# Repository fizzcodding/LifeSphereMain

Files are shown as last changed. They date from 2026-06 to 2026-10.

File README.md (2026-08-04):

# LIFESPHERE

**Health · Safety · Automation · Care**

> *An AI-Powered Autonomous Caregiving Ecosystem*

**Research paper:** [`An AI- Powered Autonomous Caregiving Ecosystem.pdf`](./An%20AI-%20Powered%20Autonomous%20Caregiving%20Ecosystem.pdf)
**Live web demo:** <https://spherecore-lite.vercel.app> — the deployed web demo; switch between App Mode and Result Mode in the header
**Android APK:** [app-release.apk](./spherecore/build/app/outputs/apk/release/app-release.apk)

What's built and working right now is SphereCore, in two forms. The Flutter companion app is the primary one, and the web demo in `hollowcore-hardware/web_demo/` is its browser counterpart with two modes: **App Mode** is a web reimplementation of SphereCore's Firebase-backed screens, so it's the same app, not a separate tool — and **Result Mode** is a read-only live mirror of HollowCore's state, updating in real time as control actions land from SphereCore (mobile or App Mode). Everything runs on the one Firebase Realtime Database backend, which is what makes a toggle in one surface show up in the others. LifeSphere as a whole is the larger goal: an autonomous caregiving ecosystem of five subsystems sharing one biological state, monitoring the user across four dimensions (medical, physical, emotional, environmental) and responding without explicit input. The whole point is that the user never has to touch a screen or say a command — the system watches their biology and reacts to that instead. The remaining subsystems are documented and scaffolded but not yet migrated in (see [Project Status](#project-status)).

## Contents

- [Local Development Setup](#local-development-setup)
- [SphereCore](#spherecore)
- [Why LifeSphere?](#why-lifesphere)
- [The Five Subsystems](#the-five-subsystems)
- [System Architecture](#system-architecture)
- [AI Model Pipeline](#ai-model-pipeline)
- [Key Features](#key-features)
- [Bill of Materials](#bill-of-materials)
- [Repository Layout](#repository-layout)
- [Project Status](#project-status)

## Local Development Setup

Here's how to get SphereCore running locally. Requires the [Flutter SDK](https://docs.flutter.dev/get-started/install) (Dart SDK `^3.10.8` per `pubspec.yaml`).

```bash
git clone https://github.com/fizzcodding/LifeSphereMain.git
cd LifeSphereMain
```

```bash
cd spherecore
flutter pub get
flutter run                      # picks a connected device / emulator
flutter build apk --release      # Android release build
```

Firebase is the backend. The repo ships with `lib/firebase_options.dart` for the `hollow-core` project; to point the app at your own Firebase project, run `flutterfire configure` and set up a Realtime Database following the LifeSphere schema (see Section 7 of the [research PDF](./An%20AI-%20Powered%20Autonomous%20Caregiving%20Ecosystem.pdf)). Note that the camera view (`ControlScreen`) and member management (`MembersScreen`) talk to hardware over the local network — an ESP32-CAM websocket on port 81 and an HTTP endpoint — so those screens won't do anything useful without the physical hardware on the same LAN.

### HollowCore web demo

The web demo runs locally too (Vite + Firebase JS SDK, needs Node.js and npm). It signs in against the same Firebase project as the app, so an account registered on mobile works here directly:

```bash
cd hollowcore-hardware/web_demo
cp .env.example .env     # Firebase web config; values mirror spherecore/lib/firebase_options.dart
npm install
npm run dev              # dev server on http://localhost:5180
```

Once it's up you'll see a mode switch in the header. **App Mode** is a read/write web version of SphereCore's Firebase-backed screens (Devices, Vital32, Reminders, Profile) — writes go to the same database paths the mobile app uses, so toggling a device here drives real hardware. **Result Mode** is a read-only mirror: toggle something from the mobile app and the corresponding tile flashes and logs the change within milliseconds, nothing polled or simulated. More detail (data model, which SphereCore screens are deliberately not reimplemented and why) in [`hollowcore-hardware/web_demo/README.md`](./hollowcore-hardware/web_demo/README.md).

## SphereCore

Since the elderly user is meant to never touch a screen, the app is the window in for guardians and family members instead. It streams the shared biological state object from Firebase Realtime Database into a live dashboard (heart rate, SpO₂, skin temperature, HRV, anomaly score, emotional state, subsystem statuses), manages medication schedules produced by the prescription OCR pipeline before HollowRover starts delivery, and controls HollowCore appliances and ecosystem modes such as Absence Mode. Guardians can add dependent members, define monitoring instructions and receive alerts for falls, intrusions, anomalies, and digital-safety events. The Flutter app builds for Android, iOS, web, and desktop, with Android as the primary target; the web demo's App Mode covers its Firebase-backed screens in the browser.

Full details, screens, and project structure: [`spherecore/README.md`](./spherecore/README.md)

## Why LifeSphere?

Bangladesh has over 15 million elderly citizens, most of whom stay home alone while family members work full-time. Every day people forget critical medication, fall with nobody nearby, and deteriorate physically and emotionally until it turns life-threatening.

**Hypothesis:** an integrated, bioresponsive caregiving ecosystem produces better outcomes than any combination of single-function devices.

Existing smart devices work in silos, a smartwatch tracks heart rate, a smart speaker sets reminders, a camera records video, and none of them talk to each other. LifeSphere ties everything to a single biological state backbone: when Vital32 detects a cortisol spike, SphereAI adjusts its tone, HollowCore changes the lighting, and HollowRover prepares a stress-relief protocol, all automatically.

## The Five Subsystems

| Subsystem | Primary Function | Core Hardware | AI Stack | Repo Directory |
|---|---|---|---|---|
| **Vital32** | Continuous biometric monitoring & home automation trigger | ESP32, MAX30102, MPU6050, MLX90614, BME688, BIA circuit (16-sensor array) | LSTM, Isolation Forest, biological age model | [`vital32/`](./vital32) |
| **HollowRover** | Physical response, medicine delivery, security patrol, passive barrier deterrence | D-Robotics RDK X5 (4GB, 10 TOPS NPU), STL-19P TOF LiDAR, DW1000 UWB, MLX90640 thermal, 6-DOF MG996R arm | SLAM, Nav2, biomarker-triggered protocol engine, DeepFace | [`hollowrover/`](./hollowrover) |
| **SphereAI** | Trimodal emotional intelligence & cognitive monitoring | Microphone, speaker, Whisper STT, OLED via rover | NLP + voice prosody + biomarker fusion classifier | [`sphereai/`](./sphereai) |
| **EntryGuard** | 24/7 intrusion, fire, and gas detection at all entry points | PIR, MQ-2 gas, KY-026 fire, ESP32 nodes | DeepFace recognition, threat classification | [`entryguard/`](./entryguard) |
| **HollowCore** | Biology-responsive home & financial automation | Wi-Fi relay modules, MQTT broker, ESP32 | Biomarker-to-environment mapping, anomaly detection | [`hollowcore-hardware/`](./hollowcore-hardware) |

### Vital32 — The Sensing Layer

A wearable the user forgets they're wearing. Its 16-sensor array captures ECG waveforms, IR skin temperature, accelerometer/gyroscope data (fall and tremor detection), bioelectrical impedance (hydration), galvanic skin response (sympathetic nervous activity), and near-infrared tissue perfusion (wound healing). The onboard AI pipeline is designed to flag immune activation 24–48 hours before symptoms appear and estimate pre-seizure probability 30 minutes before onset.

### HollowRover — The Physical Response Unit

Runs ROS2 Humble on a D-Robotics RDK X5, with SLAM floor mapping and UWB positioning targeting 10 cm accuracy. It executes biomarker-triggered protocols on its own: medication dispensing, fall response dispatch, pre-seizure cushioning, and cortisol-spike deescalation. The 6-DOF arm picks up dropped objects and hands items to the user. As a security deterrent it is passive-barrier only. No contact, no restraint, and any escalation requires human authorization.

### SphereAI — The Emotional Intelligence

A TriAgent architecture: NLP sentiment analysis, vocal prosody extraction, and live Vital32 biomarker feeds, fused by a dynamically weighted meta-classifier. This supports early cognitive decline detection and longitudinal emotional modeling. It also includes an Islamic integration framework: Salah reminders, stress-triggered Adhkar, and a Ramadan mode that restructures medication and hydration around fasting.

### EntryGuard — Perimeter Security

Multi-sensor ESP32 nodes (PIR, ultrasonic, fire, gas) at every entry point, with face recognition checked against registered profiles. It arms itself and only alerts on genuine threats.

### HollowCore — Biology-Responsive Automation

Maps physiological and emotional state directly to lighting, thermal, appliance, and digital safety outputs over Wi-Fi + MQTT. Stressed → lights dim. Cold → AC adjusts. The design also covers financial anomaly detection (Isolation Forest on spending habits) with multi-factor biometric transaction authorization.

## System Architecture

- **Shared Biological State Object** — a continuously updated JSON document on Firebase Realtime Database, the ecosystem's central nervous system. Vital32 writes, everything else subscribes (target latency: 150 ms).
- **Two-channel communication** — cloud-mediated Firebase listeners plus direct MQTT over local Wi-Fi; a 115200-baud serial bridge for sub-10ms motor commands; GSM (SIM800L) fallback during Wi-Fi outages.
- **Multi-timescale inference** — short-cycle (30 s) acute anomaly detection, medium-cycle (15 m) emotional/cortisol models, long-cycle (24 h) biological age clock and circadian modeling.
- **Fault tolerance** — 5000 mAh backup battery, 24 h local SD vital storage, HollowRover doubles as a local hotspot during outages, independent watchdog timers on all five nodes.
- **Security** — TLS in transit, face profiles stored locally (never uploaded), mandatory human authorization before any defensive action, physical-plausibility validation of all sensor readings.

## AI Model Pipeline

| Model | Architecture | Output | Threshold |
|---|---|---|---|
| Anomaly Detector | Isolation Forest (100 trees) | Score 0–1 | 0.7 / 0.9 |
| Pre-Seizure LSTM | 2×LSTM (64, 32) + Dense | Prob 0–1 | 0.85 |
| Emotional Classifier | Weighted 3-stream fusion | State category | Highest |
| Cortisol Estimator | Gradient Boost (200 trees) | ng/dL est. | 15 m update |
| Biological Age Clock | Ensemble (RF + XGBoost) | Age in years | Daily update |
| Cognitive Tracker | Statistical drift (CUSUM) | Deviation score | 2-sigma |

All models are trained offline and run on-device as TensorFlow Lite. They learn the user's own biological baseline over the first 30 days instead of comparing against a generic population.

## Key Features

- **Prescription OCR** — photograph a prescription once; OCR + LLM parsing builds the full medication schedule and syncs it to HollowRover's dispenser, with pressure-sensor adherence logging.
- **Absence Mode** — runs the household while the occupant is away: plant watering, appliance checks, patrols, full-active security, and daily photo/status reports.
- **Remote Guardian** — guardians configure monitoring for dependent family members remotely, including AI-powered digital safety (network-level content filtering, smart screen time, distress-pattern alerts).

## Bill of Materials

| Subsystem | Cost (USD) |
|---|---|
| Vital32 | $67.70 |
| HollowRover | $373.30 |
| SphereAI | $12.00 |
| EntryGuard (×2 nodes) | $36.50 |
| HollowCore | $15.00 |
| **LifeSphere Total** | **$504.50** |

## Repository Layout

```
LifeSphereMain/
├── vital32/                  # ESP32 biosensing wearable (firmware, TFLite models, web demo)
├── hollowrover/              # ROS2 rover workspace, dispenser + ESP32 peripheral sketches
├── sphereai/                 # TriAgent emotional intelligence (Python)
├── entryguard/               # ESP32 perimeter security nodes + face recognition API
├── hollowcore-hardware/      # ESP32 relay firmware, automation logic, web control panel
├── spherecore/               # Flutter companion app (dashboard, reminders, control)
├── MedicineDispenser.FCStd   # FreeCAD model of the medication dispenser
├── ResearchPaper.latex       # Research paper source
└── An AI- Powered Autonomous Caregiving Ecosystem.pdf   # Full build document
```

## Project Status

This is an active competition-stage project, not a finished product. Current state of the code, honestly:

- **Working end to end:** SphereCore in both its forms (Flutter app and the web demo's App Mode / Result Mode), plus the HollowCore ESP32 relay firmware. All of it reads and writes the same Realtime Database, so an appliance toggled in any one surface moves real hardware and shows up in the others.
- **Scaffolded:** the source trees for Vital32, HollowRover, SphereAI, and EntryGuard exist with their intended file layout, but most files are placeholders pending migration of the working code. The hardware builds, sensor integrations, and model designs for these subsystems are documented in the research PDF.
- The performance figures quoted above (150 ms sync latency, 10 cm UWB accuracy, pre-symptom detection windows) are design targets and prototype measurements from the research document, not guarantees of the code in this repo.
- The release APK linked at the top of this page lives under `spherecore/build/`, which is a build-output directory; rebuild with `flutter build apk --release` if it's absent from your checkout.

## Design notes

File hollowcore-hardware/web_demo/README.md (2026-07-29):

# HollowCore Web Demo

Browser control panel for the HollowCore automation node. It authenticates against the
same Firebase project as the SphereCore Flutter app (`hollow-core`), so an account
registered on mobile signs in here with no separate user record.

## Setup

```bash
cd hollowcore-hardware/web_demo
cp .env.example .env
npm install
npm run dev
```

The dev server listens on <http://localhost:5180>.

`.env` is gitignored. The values in `.env.example` mirror the web block of
`spherecore/lib/firebase_options.dart`, plus `VITE_FIREBASE_DATABASE_URL`, which the
Flutter SDK derives from the project ID but the JS SDK requires explicitly.

## Modes

The header carries an explicit **App Mode / Result Mode** switch. The selection persists
in `localStorage`.

**App Mode** is a read/write reimplementation of the SphereCore screens that are backed
by Firebase: Devices, Vital32, Reminders and Profile. Writes go to the same Realtime
Database paths the mobile app writes to, so toggling a device here drives real hardware.

**Result Mode** is a read-only mirror driven by `onValue` listeners. Toggle a device in
the mobile app and this view updates within milliseconds: the affected tile flashes, an
`UPDATED` badge appears, and a timestamped entry lands in the change feed. Nothing is
polled and nothing is simulated.

Two SphereCore screens are deliberately not reimplemented. `ControlScreen` talks to an
ESP32-CAM over `ws://<lan-ip>:81` and an MJPEG stream, and `MembersScreen` calls
`http://<lan-ip>/users`. Both require the reviewer to be on the same LAN as the hardware,
so they cannot work from a remote browser.

## Architecture

```
src/
  firebase/    SDK initialisation and env-backed config
  auth/        sign-in, registration, session observation
  api/         Realtime Database paths and read/write services
  realtime/    onValue subscriptions, connection monitor, pin diffing
  ui/          shell, views, reusable components
  lib/         DOM helper and formatting
  styles/      design tokens translated from spherecore AppTheme
```

The layers only depend downwards: `ui` uses `api` and `realtime`, both of which use
`firebase` and `auth`. No view talks to the Firebase SDK directly.

## Data model

Device state lives at `users/{uid}/virtualPins/{pushId}`:

```json
{ "id": "-OWLbEYsujEjrFI6SEIs", "label": "Living room light", "pin": 26, "state": false }
```

`pin` is the ESP32 GPIO number and `state` is the relay's desired level. The record's
`id` field is not authoritative; some existing rows carry a stale value, so the push key
is used instead, matching `DatabaseService.getPins()` in the Flutter app.

## Design tokens

Colours, fonts and radii are taken from `spherecore/lib/themes/app_theme.dart` and
declared as CSS custom properties in `src/styles/base.css`. SphereCore ships a light
theme (`themeProvider` is hardcoded to `ThemeMode.light`), so this panel is light too.
Poppins and the LifeSphere logos are copied from `spherecore/assets`; the logos are
cropped to their content bounds because the originals are centred on 500x500 canvases.

## Security

`database.rules.json` in the parent directory scopes every read and write to the owning
user. Deploy it before demoing:

```bash
firebase deploy --only database --project hollow-core
```

Without it the database is world-readable.

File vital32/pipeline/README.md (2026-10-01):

# Vital32 AI Model Training Pipeline

Offline model training and TFLite export pipeline for the Vital32 wearable biosensor node (LifeSphere project). Models are trained on a dev machine and deployed to the ESP32 WROOM-32 firmware.

## Quick start

```bash
cd vital32
python -m venv venv
source venv/bin/activate
pip install tensorflow scikit-learn xgboost scipy mne pyedflib joblib
```

Run all training scripts in order:

```bash
python pipeline/models/train_anomaly_forest.py
python pipeline/models/train_seizure_lstm.py
python pipeline/models/train_cortisol_estimator.py
python pipeline/models/train_bio_age_estimator.py
```

Run all tests:

```bash
python pipeline/tests/test_signal_processing.py
python pipeline/tests/test_anomaly_forest.py
python pipeline/tests/test_seizure_lstm.py
python pipeline/tests/test_cortisol.py
python pipeline/tests/test_bio_age.py
```

---

## What is demo-ready

These components run end to end and produce verified output:

**Signal processing layer** (`pipeline/signal_processing/`)
- PPG peak detection and RR interval extraction from MAX30102 raw IR signal (`ppg_peaks.py`). Bandpass 0.5–4 Hz, scipy `find_peaks`, physiological RR filter (300–2000 ms), ectopic beat artifact removal.
- HRV feature computation (`hrv_features.py`). RMSSD via `sqrt(mean(diff(RR)^2))`, LF/HF ratio via Welch PSD with cubic-spline RR interpolation at 4 Hz, LF 0.04–0.15 Hz, HF 0.15–0.40 Hz.
- SpO2 derivation from raw IR/Red PPG (`spo2.py`). Beer-Lambert ratio-of-ratios: `R = (AC_red/DC_red) / (AC_ir/DC_ir)`, `SpO2 = 110 − 25×R`. Maxim Integrated default coefficients. Includes per-beat AC amplitude estimation, signal quality flag, and sliding-window batch processing. Verified: normal scenario gives SpO2 97.1% with R≈0.52, as expected.
- ECG R-peak detection from AD8232 raw waveform (`ecg_peaks.py`). Pan-Tompkins-style: bandpass 5–15 Hz → differentiate → square → 150 ms moving-window integrate → adaptive threshold → local max refinement. Clean synthetic ECG at 75 bpm: 75 peaks detected, RR mean 800 ms, SNR 25.8 dB. Noisy signal correctly flagged quality_ok=False.

**Anomaly detector** — Isolation Forest, 100 trees, contamination=0.05
- Trained on synthetic 30-day per-user baseline (86,400 30-second rolling-window feature vectors, 11 features).
- Normalization calibrated from training data: `score = (df_max − df) / (df_max − df_min)` where df is `decision_function` output and bounds are the 1st/99th percentiles of training data. This fixed a bug in the previous version where all scores were near zero.
- Crisis sample (HR=145, SpO2=87, RMSSD=1.5) scores 1.0. Normal baseline median score ≈ 0.35. Alert rate on training data ≈ 6.4% at the 0.7 threshold (consistent with contamination=0.05).
- TFLite approximator: 4-layer Dense network trained to replicate IF scores. Exports to `models/anomaly_forest.tflite` (11 KB). TFLite inference verified on desktop Python.

**Cortisol estimator** — GradientBoostingRegressor, 200 trees
- Inputs: RMSSD (ms), GSR (µS), skin temperature (°C), sleep efficiency (0–1).
- Synthetic proxy: low-stress 2.4 ng/dL, high-stress 7.4 ng/dL, morning peak 20.1 ng/dL. Physiologically directionally correct.
- Saved as `models/cortisol_estimator.joblib` + `models/cortisol_scaler.joblib`.

**Biological age estimator** — RandomForest (200 trees) + XGBoost (200 trees) ensemble
- 11 input features spanning all sensor channels.
- Inference: healthy 65-year-old → 51 years estimated, deconditioned 72-year-old → 93 years estimated.
- Saved as `models/bio_age_rf.joblib`, `models/bio_age_xgb.joblib`, `models/bio_age_scaler.joblib`.

**Pre-seizure LSTM** — architecture as specified
- Input shape `(300, 5)`. Feature definitions: columns 0–3 are EEG band powers (delta, theta, alpha, beta, log-normalized); column 4 is HRV RMSSD (normalized to [0,1]).
- Architecture: `LSTM(64, return_sequences=True) → Dropout(0.3) → LSTM(32) → Dropout(0.3) → Dense(16, relu) → Dense(1, sigmoid)`.
- Keras model inference verified: pre-ictal sequence probability 1.0, interictal 0.0001 on synthetic data.
- TFLite export uses `SELECT_TF_OPS` (Flex delegate) because standard TFLite does not support `return_sequences=True` LSTM with dynamic shapes. File exports correctly (61 KB). On-device Android requires `org.tensorflow:tensorflow-lite-select-tf-ops` dependency. The Python desktop interpreter cannot run Flex-delegate TFLite models; this is expected and documented.

---

## What is synthetic-only

Every model in this pipeline was trained on procedurally generated data. No model has been validated on real user measurements.

**Anomaly Forest** — trained on synthetic 30-day baseline data from `pipeline/synthetic/baseline_generator.py`. The score distribution and threshold behavior is calibrated to synthetic physiological distributions. Retraining on 30 days of real per-user data will change the calibration constants and the alert rates.

**Cortisol Estimator** — no public wearable dataset pairs GSR/HRV/temperature readings with biochemically validated cortisol concentrations (ELISA or mass spectrometry). The proxy target is constructed from literature-derived direction-of-effect relationships (Thayer 2012, Nater 2006, Kudielka 2009, Vgontzas 1997). [SYNTHETIC-DERIVED] test MAE 1.85 ng/dL, R² 0.81 — these numbers measure proxy self-consistency, not clinical accuracy.

**Biological Age Estimator** — no public wearable dataset provides simultaneously collected sensor data and validated biological age labels (Horvath methylation clock, Levine PhenoAge, or equivalent). The proxy target adjusts chronological age by sensor-derived health indicators. [SYNTHETIC-DERIVED] ensemble MAE 3.6 years, R² 0.86 — same caveat.

**Pre-seizure LSTM** — see domain mismatch section below.

---

## Domain mismatch: seizure LSTM

**This is the most important limitation in the entire pipeline.**

The CHB-MIT Scalp EEG dataset (PhysioNet `chbmit/1.0.0`) provides 23-channel scalp EEG at 256 Hz from pediatric epilepsy patients. The model learns pre-ictal patterns from EEG spectral features.

Vital32 hardware has no EEG channels. The 16-sensor array includes MAX30102 (PPG/SpO2), AD8232 (single-lead ECG), MPU6050 (accelerometer), MLX90614 (skin temperature), BME688 (environmental), and GSR. None of these produce EEG-band spectral information.

Consequence: features 0–3 of the `(300, 5)` input (delta, theta, alpha, beta band power) cannot be computed from Vital32 in real-time. Only feature 4 (HRV RMSSD) is available from Vital32 hardware today.

The CHB-MIT EDF files were not downloaded during training (PhysioNet connection too slow for 42 MB files at ~35 KB/s). The model trained on synthetic data that mimics pre-ictal EEG spectral structure. All reported metrics are [SYNTHETIC-DERIVED].

**What would make this model clinically usable:**
1. A dry-electrode EEG peripheral added to Vital32 hardware (e.g., TGAM1 or Emotiv INSIGHT chip) — this is documented as a planned Vital32 v2 feature.
2. CHB-MIT EDF files downloaded and the real loader path exercised (`load_chbmit_data('chb01')`).
3. Retraining on real per-user HRV + EEG data.

The CHB-MIT loader code is fully implemented in `train_seizure_lstm.py`. Place EDF files in `data/chb-mit/` alongside the `chb01-summary.txt` that is already present, and rerun the script — it will automatically use real data instead of synthetic.

---

## What needs real user data before caregiving deployment

| Component | What it needs | Minimum viable dataset |
|---|---|---|
| Anomaly Forest | 30-day per-user baseline at 30s sampling | 86,400 samples per user |
| Cortisol Estimator | Simultaneous wearable + saliva samples (morning, noon, evening) | ≥50 users × 7 days |
| Biological Age Estimator | Validated biological age labels (DNA methylation or clinical composite) | Hundreds of users, longitudinal |
| Seizure LSTM | EEG peripheral hardware or wearable pre-ictal correlates dataset | CHB-MIT + dry-EEG peripheral |

None of the deployed `.joblib` or `.tflite` files are safe to use for clinical decision-making in their current state. The anomaly forest and cortisol estimator are the closest to production-ready once real user data is collected; both have well-defined data collection requirements and no missing hardware dependencies.

---

## Repository layout

```
vital32/
├── models/                          # Trained model artifacts
│   ├── anomaly_forest.joblib        # Isolation Forest (sklearn)
│   ├── anomaly_scaler.joblib        # StandardScaler for IF
│   ├── anomaly_calibration.joblib   # df_min/df_max normalization bounds
│   ├── anomaly_forest.tflite        # TFLite approximator (11 KB)
│   ├── seizure_lstm.keras           # Keras LSTM model
│   ├── seizure_lstm.tflite          # TFLite (Flex delegate, 61 KB)
│   ├── cortisol_estimator.joblib    # GradientBoostingRegressor
│   ├── cortisol_scaler.joblib       # StandardScaler for cortisol
│   ├── bio_age_rf.joblib            # RandomForest
│   ├── bio_age_xgb.joblib           # XGBoost
│   └── bio_age_scaler.joblib        # StandardScaler for bio age
│
├── pipeline/
│   ├── signal_processing/
│   │   ├── ppg_peaks.py             # PPG peak detection, RR extraction
│   │   ├── hrv_features.py          # RMSSD, LF/HF, SDNN
│   │   ├── spo2.py                  # Beer-Lambert SpO2 derivation
│   │   └── ecg_peaks.py             # Pan-Tompkins ECG R-peak detection
│   │
│   ├── synthetic/
│   │   └── baseline_generator.py   # Synthetic 30-day baseline data
│   │
│   ├── models/
│   │   ├── train_anomaly_forest.py
│   │   ├── train_seizure_lstm.py
│   │   ├── train_cortisol_estimator.py
│   │   └── train_bio_age_estimator.py
│   │
│   └── tests/
│       ├── test_signal_processing.py
│       ├── test_anomaly_forest.py
│       ├── test_seizure_lstm.py
│       ├── test_cortisol.py
│       └── test_bio_age.py
│
└── data/
    └── chb-mit/
        └── chb01-summary.txt        # CHB-MIT seizure annotations
                                     # (place chb01_*.edf here when available)
```

---

## Firebase integration

The pipeline outputs map directly to the Firebase Realtime Database schema at `/lifesphere/vital32/`:

| Firebase field | Source | Update cycle |
|---|---|---|
| `anomaly_score` | `anomaly_forest.tflite` | Every 30-second window |
| `seizure_prob` | `seizure_lstm.tflite` | Every 300-step window (~5 min at 1 Hz) |
| `cortisol_est` | `cortisol_estimator.joblib` | Every 15 minutes |
| `bio_age` | `bio_age_rf.joblib` + `bio_age_xgb.joblib` | Daily |
| `hrv_rmssd` | `hrv_features.py` | Every RR series update |
| `hrv_lf_hf` | `hrv_features.py` | Every 30-second window |
| `spo2` | `spo2.py` | Every 8-second window |

Anomaly threshold behavior: `anomaly_score > 0.7` → soft alert to SphereCore dashboard; `anomaly_score > 0.9` → emergency alert. Seizure threshold: `seizure_prob > 0.85` → HollowRover pre-seizure cushioning protocol.

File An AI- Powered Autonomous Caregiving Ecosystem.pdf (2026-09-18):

# LIFESPHERE

## Health · Safety · Automation · Care

## An AI-Powered Autonomous Caregiving Ecosystem

Complete Technical Research and Build Document

“Forged. Wired. Perfected”

LIFESPHERE Team Fälschen

LIFESPHERE | Team Fälschen

## Team Fälschen

Faiyaz Bin Iqbal

Roll: 1219 | ID: 250485 | Class: VII | Section: L
Institution: Birshreshtha Munshi Abdur Rouf Public College

As the sole engineer and researcher behind the LifeSphere project, Faiyaz Bin Iqbal independently executed its entire technical scope, from conceptual research to full-stack deployment. He conducted all core research and designed every subsystem architecture, including documenting biosensor integration methodologies and independently sourcing and curating all biomedical datasets. Driving the project’s artificial intelligence, he developed the trimodal LLM pipeline, built and trained machine learning models, and prepared the specific data pipelines for Vital32’s LSTM-based predictive health models. His software engineering contributions encompass architecting the complete infrastructure, developing autonomous agent systems, engineering the embedded backend pipeline to manage cross-subsystem data transfer, building the Firebase real-time communication layer, and designing and launching the documentation web platform. Rounding out the project’s physical and visual capabilities, he programmed full computer vision systems, designed all PCB layouts, engineered the complete robotics kinematics and manipulation systems, and rigorously tested and validated the autonomous medication dispensing and dosage mechanisms.

## Contents

Contents | 3
Abstract | 4
1 Introduction and Motivation | 6
2 System Architecture Overview | 7
3 Vital32: Complete Build Guide | 12
4 HollowRover: Complete Build Guide | 15
5 SphereAI: Implementation Guide | 22
6 EntryGuard and HollowCore: Implementation Guide | 24

7 Firebase Backend Architecture | 27
8 AI Model Pipeline: Training and Deployment | 28
9 Mathematical Foundations | 30
10 Prescription OCR and Automated Medication Reminders | 32
11 Conclusion | 35
References | 36

## Abstract

LifeSphere is a fully integrated, AI-powered autonomous caregiving ecosystem comprising five interconnected subsystems: Vital32, HollowRover, SphereAI, EntryGuard, and HollowCore. Collectively, they function as a single synchronized intelligence capable of monitoring, predicting, and responding to the user across four simultaneous dimensions: medical, physical, emotional, and environmental, without requiring continuous human supervision or explicit user input.
Vital32 is the primary biosensing layer, implemented on ESP32 microcontroller architecture with a 15-sensor array acquiring ECG waveforms, infrared skin temperature, accelerometer and gyroscope data for fall and tremor detection, bioelectrical impedance for tissue hydration quantification, galvanic skin response for sympathetic nervous system activity monitoring, and near-infrared tissue perfusion measurements for wound healing assessment. An onboard AI pipeline combining Isolation Forest anomaly detection and LSTM sequential modeling enables immune activation detection 24 to 48 hours prior to symptom onset, pre-seizure probability estimation 30 minutes before onset, and continuous biological age estimation through multi-sensor data fusion. All biometric data is transmitted in real time to Firebase Realtime Database, serving as the shared state input for all downstream subsystems.
HollowRover is the autonomous physical response unit operating on ROS2 with SLAM-based mapping, three-anchor UWB precision positioning accurate to within 10 centimeters, and barometric floor-level sensing for multi-floor deployment. Sensor fusion across TOF LiDAR, IMU, ultrasonic arrays, thermal camera, UWB, and barometric pressure allows the rover to determine both its horizontal position and current floor context before executing navigation or response protocols. EntryGuard nodes installed at protected entry points also carry UWB and barometric sensing, extending the same localization reference across monitored floors and allowing HollowRover to identify the correct floor and navigate toward the relevant EntryGuard zone during danger or intrusion events. A dedicated NPU on the D-Robotics RDK X5 compute board allows AI inference and SLAM navigation to run on separate silicon, eliminating CPU contention. BLE RSSI direction-finding remains available as a fallback when the user is outside UWB anchor coverage. HollowRover executes biomarker-triggered action protocols autonomously including medication dispensing, fall response dispatch, pre-seizure cushioning deployment, and cortisol-spike deescalation without manual command input. A 6-DOF robotic arm provides caregiving assistance (retrieving dropped objects, handing items to the user) and serves as a passive physical barrier during security response events.
SphereAI implements a trimodal emotional state classification architecture fusing NLP sentiment analysis, vocal prosody extraction, and live Vital32 biomarker feeds via a dynamic weighted meta-classifier. This enables early cognitive decline detection and longitudinal emotional state modeling. An Islamic integration framework provides salah reminders, stress-triggered adhkar, and a Ramadan mode restructuring medication and hydration protocols around fasting intervals.
EntryGuard implements perimeter security through PIR, ultrasonic, fire, gas, UWB, and barometric sensors at monitored entry points with face recognition cross-referenced against registered profiles. Its UWB and pressure data also provide floor-aware localization references for HollowRover, allowing the rover to navigate to the correct protected zone when an intrusion or environmental danger event is raised. HollowCore maps physiological and emotional state variables directly to lighting, thermal, appliance, and digital safety outputs via Wi-Fi and MQTT protocol. LifeSphere does not require the user to interact with technology. It requires technology to respond to the user’s biology.

## 1 Introduction and Motivation

Bangladesh is home to over 15 million elderly citizens, the majority of whom remain at home while family members work full-time. Every day, thousands forget critical medication, sustain falls with no one nearby to respond, and experience silent physical and emotional deterioration that goes undetected until it becomes life-threatening. Conditions detectable weeks in advance remain untreated due to limited healthcare accessibility, inadequate emergency response infrastructure, and the fundamental inability of current smart devices to act on the data they collect.

Problem Statement & Hypothesis

An elderly person living alone has no system that simultaneously monitors their health, responds to emergencies physically, provides emotional support, and protects their home, all autonomously, without requiring any action from the user.
Hypothesis: A fully integrated, bioresponsive caregiving ecosystem provides superior caregiving outcomes compared to any combination of existing single-function devices. LifeSphere unifies health monitoring, autonomous robotics, emotional AI, home security, and environmental automation into a single organism sharing one biological state backbone. This document provides complete specifications sufficient to replicate the entire system from scratch, including circuit diagrams, firmware architecture, ROS2 package structure, AI model training procedures, and Firebase schema definitions.

Impact on Humanity

LifeSphere addresses the global crisis of elderly isolation and inadequate care. By autonomously bridging the gap between biological signals and physical intervention, it preserves human dignity, prevents preventable fatalities, and ensures that the most vulnerable members of society are never truly alone.

Deployment Scope

HollowRover is not restricted to a single-floor deployment. Each deployed floor can be registered using three fixed UWB anchors for 2D positioning together with a barometric pressure reference for floor-level discrimination. HollowRover carries its own barometric pressure sensor and combines its measured pressure with the active UWB anchor set to determine which mapped floor it occupies before enabling autonomous navigation. EntryGuard nodes also include UWB and barometric sensing, so intrusion, fire, gas, or other danger events contain both a local position reference and a floor reference. HollowRover can therefore select the correct stored floor map, localize against that floor’s UWB infrastructure, and navigate to the EntryGuard zone that generated the event. The rover remains a wheeled platform and does not physically climb stairs; movement between floors therefore assumes an accessible inter-floor path such as a lift, ramp, or manual relocation. Once placed on a registered floor, the combined UWB–barometric architecture allows safe autonomous deployment and floor-aware response without treating the system as a single-floor robot.

## 2 System Architecture Overview

LifeSphere operates as a single distributed intelligence system across five hardware nodes sharing one unified data backbone. The architecture follows a publish-subscribe model with Firebase Realtime Database as the central biological state synchronization layer. Vital32 continuously writes physiological data to the shared state object. All remaining subsystems subscribe to relevant state fields and execute responses within a target latency of 150 milliseconds.

### 2.1 Ecosystems Overview & Functionality

Subsystem | Primary Function | Core Hardware | AI Stack
Vital32 | Continuous biometric monitoring and home automation trigger
ESP32, | MAX30102,
| | MPU6050, MLX90614, BME688, BIA circuit
LSTM, | Isolation
| | | Forest, biological age model
HollowRover Physical | response,
| medicine delivery, se- curity patrol, passive
barrier | deterrence,
BLE | person-finding,
multi-floor | localiza-
| tion | D-Robotics RDK X5 (4GB), STL-06P TOF
LiDAR, | DWM1000
| | UWB (×3 anchors per deployed floor),
barometric | pressure
sensor, | BNO080,
| | BLE RSSI module,
MLX90640 | thermal,
| | MG996R arm

SLAM, Nav2, floor-
aware | UWB | local-
ization, | biomarker-
triggered | protocol
engine, | DeepFace,
RSSI | direction-
finding
SphereAI | Trimodal | emotional
intelligence and cognitive monitoring
INMP441 | mic,
MAX98357A | amp
+ speaker, ESP32-S3
(local wake-word),
Whisper STT, OLED
via rover

NLP + voice prosody
+ biomarker fusion
classifier

EntryGuard 24/7 intrusion, fire, and gas detection with
floor-aware rover dispatch
PIR, | MQ-2 | gas,
KY-026 fire, ESP32,
UWB, barometric
pressure sensor

DeepFace recognition,
threat | classification,
floor-aware | localiza-
tion reference

HollowCore Biology-responsive home and financial
automation, medicine
dispenser HMI
Wi-Fi | relay | mod-
ules, MQTT broker,
ESP32, | 3.5-inch
ILI9488 | SPI | TFT
LCD with XPT2046
touch controller

Biomarker-toenvironment mapping, anomaly detection

Vital32: The Sensing Layer

How it Works: Vital32 continuously monitors the user’s physiological state using a 15-sensor array. It processes raw ADC readings, applies signal processing like HRV calculation, and feeds the data into multi-timescale AI models.
How it is Used: Worn by the user, it operates invisibly, requiring no interaction. It acts as the biological heartbeat of the entire ecosystem.
Humanity Impact: By shifting healthcare from reactive to proactive, Vital32 detects anomalies and predicts medical emergencies (like seizures or immune activation) hours or days before they become critical, saving lives through early intervention.

HollowRover: The Physical Response Unit

How it Works: Operating on ROS2 with SLAM, three-anchor UWB positioning, and barometric floor sensing, HollowRover maintains separate maps and localization references for registered floors. The rover compares its own pressure reading with stored floor baselines and the active UWB anchor set to select the correct floor map before autonomous navigation. EntryGuard nodes provide matching UWB and barometric references, allowing an intrusion or danger alert to identify both the target zone and floor so HollowRover can navigate to it once an accessible inter-floor route has placed the rover on that level. It subscribes to Firebase and executes physical protocols when specific biomarker thresholds are crossed. When the user is outside UWB anchor coverage or in a different room, BLE RSSI direction-finding enables the rover to actively search for and navigate toward the user’s wearable. A 6-DOF robotic arm provides caregiving assistance and passive security barrier functions.
How it is Used: It roams the home dispatching medication, responding to falls, retrieving dropped objects, and patrolling. It bridges the gap between digital alerts and physical action.
Humanity Impact: Ensures that no one remains on the floor after a fall and that critical medications are never missed. It provides a physical presence that purely digital systems cannot offer.

SphereAI: The Emotional Intelligence

How it Works: SphereAI fuses NLP sentiment analysis, vocal prosody, and live biomarkers using a dynamic meta-classifier to assess emotional and cognitive states. It listens and processes, adapting its weights based on prior emotional context. An ESP32-S3 runs a local wake-word detection model, enabling always-listening capability without continuous cloud connectivity. Audio I/O uses an INMP441 I2S digital microphone for input and a MAX98357A I2S Class D amplifier with speaker for output.
How it is Used: It engages in natural conversation, provides verbal companionship, and triggers cultural/spiritual reminders like Salah or Adhkar based on emotional need. Humanity Impact: Fights the silent epidemic of elderly loneliness and cognitive decline. It provides empathetic interaction and early detection of neurological deterioration.

EntryGuard: Perimeter Security

How it Works: Deploys multi-sensor nodes (PIR, ultrasonic, fire, gas, UWB, and barometric pressure) at monitored entry points. Uses facial recognition to distinguish between registered occupants and intruders, publishing alerts to Firebase together with the Entry-Guard node identity, UWB zone reference, and floor-level pressure reference. HollowRover uses this information to select the correct mapped floor and navigate to the EntryGuard location associated with the danger or intrusion event.
How it is Used: Operates continuously as an invisible security layer. It arms automatically and alerts only when genuine threats are detected.
Humanity Impact: Provides peace of mind and physical safety for vulnerable individuals living alone, protecting against both environmental hazards and intrusions.

HollowCore: Biology-Responsive Automation

How it Works: HollowCore maps the user’s physiological and emotional state directly to the home environment via Wi-Fi relays and MQTT. Cortisol spikes trigger warm ambient lighting and lower AC temperature to promote calm. Elevated GSR activates a calming audio playlist via SphereAI’s speaker. Low SpO2 readings activate an air purifier relay. Sleep-detected states (determined by HRV combined with accelerometer immobility from Vital32) trigger a lights-off and door-lock protocol. Skin temperature below baseline raises the AC thermostat. The medication dispenser features a 3.5-inch 480x320 ILI9488 SPI TFT LCD with an XPT2046 touch controller connected directly to an ESP32, providing a manual fallback input method when phone-based prescription OCR is not used. The ESP32 renders the user interface directly using the TFT_eSPI Arduino library and polls the XPT2046 touch controller for touch coordinates, allowing the user or caregiver to select medications, confirm dosages, and review schedules directly on the rover. HollowCore also monitors financial transactions for anomalies using an Isolation Forest model trained on the user’s historical spending patterns, with biometric transaction authorization requiring facial recognition, fingerprint, and Vital32 proximity confirmation for high-risk transactions.
How it is Used: Operates entirely in the background. The home becomes a living organism that adapts to the user’s biology without switches or commands.
Humanity Impact: Creates a therapeutic environment that reduces stress and enhances comfort, making the home an active participant in caregiving rather than a passive container.

### 2.2 How the Unified Ecosystem Helps Humanity

While individual subsystems target specific needs, the unified LifeSphere ecosystem creates a paradigm shift in caregiving. Traditional smart devices operate in silos—a smartwatch tracks heart rate, a smart speaker sets reminders, a security camera records video. LifeSphere unifies these into a single biological state backbone. When Vital32 detects a cortisol spike, SphereAI adjusts its tone, HollowCore alters the lighting, and HollowRover prepares a stress-relief protocol. This multi-dimensional, synchronized response ensures that the user is cared for holistically—medically, physically, emotionally, and environmentally. By removing the need for the user to interact with technology, LifeSphere serves those who need care the most but are least capable of managing complex devices.

### 2.3 Distributed Intelligence Model

Each subsystem maintains local processing capability while simultaneously contributing to and consuming from the shared Firebase state object. This architecture ensures no single point of failure exists for user monitoring. If HollowRover is charging, Vital32 still monitors. If one ESP32 node fails, remaining nodes continue operating independently.

### 2.4 Shared Biological State Object

The core architectural primitive of LifeSphere is the biological state object: a continuously updated JSON document on Firebase containing the user’s complete physiological, emotional, and environmental profile.

Listing 1: Firebase JSON Schema

{
" lifesphere ": {
" vital32 ": {
" heart_rate ": 72 , " spo2 ": 98.2 , " skin_temp ": 36.4 , " hrv_rmssd ": 42.1 , " hrv_lf_hf ": 1.8 , " gsr ": 0.34 , " bio_age ": 68.4 , " anomaly_score ": 0.12 ,
" seizure_prob ": 0.03 , " cortisol_est ": 14.2 ,
" fall_detected ": false , " immune_alert ": false ,
" timestamp ": 1720000000000
},
" sphereai ": {
" emotional_state ": " calm ", " stress_level ": 0.21 , " loneliness_index ": 0.15 , " cognitive_score ": 0.94 },
" hollowrover ": { " status ": " idle " , " battery ": 87 },
" hollowcore ": { " ac_temp ": 24 , " fan ": false },
" entryguard ": { " mode ": " passive " , " intruder_detected ": false } }
}

### 2.5 Inter-Subsystem Communication Protocol

Subsystem communication follows a two-channel model. Cloud-mediated signals use Firebase Realtime Database listeners with target latency of 150ms. Hardware-to-hardware low-latency commands use direct MQTT over local Wi-Fi. HollowRover maintains a direct serial bridge to the ESP32 peripheral controllers at 115200 baud for motor and actuator commands requiring sub-10ms response times. GSM via SIM800L module serves as the fallback communication channel during Wi-Fi outages.

### 2.6 Multi-Timescale Inference Architecture

The AI inference pipeline operates across three simultaneous timescales:
- Short-cycle (30s): Runs on the normalized biometric feature vector for acute anomaly detection.
- Medium-cycle (15m): Updates emotional state and cortisol estimation models.
- Long-cycle (24h): Updates biological age clock, cognitive baseline deviation score, and personalized circadian rhythm model over a 30-day rolling window.

### 2.7 Fault Tolerance and Graceful Degradation

HollowRover carries a 5000mAh LiPo backup battery maintaining all critical operations during power outages and stores the last 24 hours of vital data locally on SD card. During Wi-Fi outages, HollowRover activates as a local Wi-Fi hotspot enabling Vital32 to continue transmitting. All five subsystems implement independent watchdog timers triggering reconnection attempts and guardian notifications upon detecting unresponsive nodes.

### 2.8 Security and Data Integrity

All biometric and personal data transmitted between subsystems and Firebase uses TLS encryption in transit. Face recognition profile data is stored locally on HollowRover and never transmitted to external servers. The intruder response protocol implements a mandatory human authorization step before any defensive action executes. Sensor readings are validated against physical plausibility bounds before entering the inference pipeline, filtering hardware faults from genuine biological anomalies.

## 3 Vital32: Complete Build Guide

Vital32 is the primary biosensing node of LifeSphere. It is built on the ESP32 WROOM-32 microcontroller and communicates with Firebase via Wi-Fi. This section provides complete wiring specifications, firmware architecture, and sensor calibration procedures sufficient to build and deploy a functional Vital32 unit from scratch.

### 3.1 Complete Component List

Component | Model / Part Number | Qty
Microcontroller | ESP32 | WROOM-32 | DevKit | v1
(SPI/I2C/ADC/GPIO)

1

Heart Rate + SpO2 | MAX30102 breakout board (I2C 0x57) | 1
IMU (Fall + Tremor) | MPU6050 breakout board (I2C 0x68) | 1
IR Temperature | MLX90614 breakout board (I2C 0x5A) | 1
VOC + Humidity | BME688 breakout board (I2C 0x76) | 1
UV Sensor | VEML6075 breakout board (I2C 0x10) | 1
Galvanic Skin Response Grove GSR v1.0 or custom 2-electrode (ADC
| GPIO35)

1

Bioelectrical Impedance AD5933 impedance converter (I2C 0x0D) | 1
Near-IR Wound | 850nm LED + BPW34 photodiode + opamp (ADC
| GPIO36)

1

OLED Display | SSD1306 0.96 inch 128x64 (I2C 0x3C) | 1
LiPo Battery | 3.7V 1000mAh LiPo + TP4056 charger | 1
Charging Module | TP4056 with protection, USB-C input | 1
3.3V Regulator | AMS1117-3.3 or ESP32 onboard VIN | 1

### 3.2 Wiring and Pin Configuration

All I2C sensors share the SDA and SCL bus on GPIO21 and GPIO22 respectively. Each sensor has a unique I2C address allowing coexistence on one bus.

Listing 2: ESP32 Pin Assignments

// I2C Bus ( shared ):
GPIO21 ( SDA ) -> MAX30102 , MPU6050 , MLX90614 , BME688 , VEML6075 , AD5933 , SSD1306 SDA GPIO22 ( SCL ) -> MAX30102 , MPU6050 , MLX90614 , BME688 , VEML6075 , AD5933 , SSD1306 SCL
3.3 V -> VCC of all I2C modules | GND -> GND of all I2C modules

// Analog Inputs :
GPIO35 ( ADC1_CH7 ) -> GSR sensor signal output
GPIO36 ( ADC1_CH0 ) -> NIR photodiode amplifier output

// NIR Wound Healing Circuit :
GPIO32 ( OUTPUT ) -> 850 nm LED anode via 100 ohm current - limiting resistor BPW34 photodiode -> cathode to 3.3 V , anode to inverting input of LM358 LM358 opamp -> configured as transimpedance amplifier , gain 100 k
LM358 output -> GPIO36

// Power :
LiPo 3.7 V -> TP4056 BAT + BAT -
TP4056 OUT + OUT - -> AMS1117 -3.3 IN GND AMS1117 -3.3 OUT -> ESP32 3.3 V pin
USB -C -> TP4056 IN + IN - for charging

### 3.3 Firmware Architecture

The Vital32 firmware is written in Arduino C++ using the ESP32 Arduino Core. The main loop runs at 50Hz. Sensor reads are distributed across ticks using a scheduler to avoid I2C bus contention.

Listing 3: Vital32 Main Loop

void loop () {
uint32_t t = millis () ;
// Every tick (20 ms ) :
readMPU6050 () ; | // accel + gyro at 50 Hz for fall detection
runFallDetector () ;
// Every 1 second :
if (t % 1000 == 0) {
readMAX30102 () ; readMLX90614 () ; readGSR () ; calculateHRV () ; runAnomalyScorer () ; updateOLED () ; }
// Every 5 seconds :
if (t % 5000 == 0) {
readBME688 () ; readVEML6075 () ; readNIR () ;
readBIA () ; runSeizureDetector () ; // LSTM on rolling window }
// Every 30 seconds :
if (t % 30000 == 0) {
runBioAgeModel () ; writeToFirebase () ; }
}

### 3.4 Fall Detection Algorithm

Fall detection uses a two-stage algorithm on the MPU6050 accelerometer data. Stage 1 detects a freefall event by checking if the resultant acceleration magnitude drops below 0.4g. Stage 2 detects the impact by checking if the magnitude exceeds 2.5g within 500ms of the freefall. A zero-movement condition sustained for 3 seconds post-impact confirms the fall.

Listing 4: Fall Detection Implementation

bool detectFall ( float ax , float ay , float az ) { float magnitude = sqrt ( ax * ax + ay * ay + az * az );
if ( magnitude < 0.4) {
freefallTime = millis () ; freefallDetected = true ; }
if ( freefallDetected && magnitude > 2.5) {
if ( millis () - freefallTime < 500) { impactDetected = true ; impactTime = millis () ; }
}
if ( impactDetected && magnitude < 1.1) {
if ( millis () - impactTime > 3000) { freefallDetected = false ; impactDetected = false ; return true ; // confirmed fall
}
}
return false ;
}

### 3.5 HRV Calculation

Heart Rate Variability is computed from the RR interval series extracted from the MAX30102 PPG signal. RMSSD is computed over a 2-minute rolling window of RR intervals. LF/HF ratio is computed via Welch PSD on the RR series.

Listing 5: RMSSD Calculation

float calculateRMSSD ( float * rr_intervals , int n ) { float sum_sq_diff = 0.0;
for ( int i = 0; i < n -1; i ++) {
float diff = rr_intervals [i +1] - rr_intervals [ i ]; sum_sq_diff += diff * diff ;
}
return sqrt ( sum_sq_diff / (n - 1) );
}
// LF band : 0.04 -0.15 Hz | HF band : 0.15 -0.40 Hz
// Computed using arduinoFFT library on 256 - sample RR window

## 4 HollowRover: Complete Build Guide

HollowRover is the autonomous physical response unit of LifeSphere. It runs ROS2 Humble on a D-Robotics RDK X5 (4GB) and uses a floor-aware navigation architecture combining SLAM, three-anchor UWB precision localization, and barometric pressure sensing. Separate floor maps can be registered with their own UWB anchor geometry and pressure baseline, allowing the rover to determine the active floor context before navigating. EntryGuard UWB and barometric references extend this architecture to security events by identifying the floor and protected zone requiring response. The drivetrain employs a four-wheel rocker suspension with spring-loaded pivots and a rear differential bar for maintained ground contact over uneven surfaces. A 6-DOF robotic arm provides caregiving assistance and passive security barrier functionality.

### 4.1 Complete Component List

Component | Model / Part Number | Qty
Main Computer | D-Robotics RDK X5 4GB (8-core Cortex-A55, 10 TOPS NPU, Wi-Fi 6/BT 5.4) | 1
Drivetrain MCU | ESP32 WROOM-32 DevKit v1 (UART to RDK X5, SPI, PWM) | 1
Manipulator MCU | ESP32 WROOM-32 DevKit v1 (UART to RDK X5, I2C, PWM) | 1
LiDAR | STL-19P TOF LiDAR (innomaker), 12m range, 5000Hz, 60000Lux anti-glare | 1
IMU | MPU9250 9-axis (I2C 0x68 to Drivetrain ESP32) | 1
Ultrasonic x4 | HC-SR04 (GPIO on Drivetrain ESP32) | 4
Thermal Camera | MLX90640 32x24 (I2C 0x33 to RDK X5) | 1
RGB Camera | USB 1080p wide-angle (USB to RDK X5) | 1
UWB Anchor Set | Decawave DW1000/DWM1000 fixed anchors, three per registered floor | 3 per floor

Barometric Floor Sensor BME688 pressure sensor (I2C to Drivetrain
| ESP32) | 1
Motor Driver | L298N dual H-bridge (GPIO PWM from Driv- etrain ESP32) | 1
DC Motors x4 | 12V 200RPM gear motor with encoder | 4
Rocker Suspension | Spring-loaded pivot per rocker arm + rear dif- ferential bar | 1 set
Robotic Arm Servos | MG996R metal gear (base, shoulder, elbow, wrist pitch, wrist roll) | 5
Gripper Servo | MG90S (gripper) | 1
Arm ToF Sensor | TF-Luna single-point ToF 0.2–8m (UART/I2C to Manipulator ESP32) | 1
Main Battery | LiPo 11.1V 5000mAh (3S) with XT60 connec- tor | 1
Medication Dispenser | 4x SG90 servo + pill compartments (PWM from Manipulator ESP32) | 1
Water Spray | 5V mini peristaltic pump + 100ml tank (GPIO relay from Manipulator ESP32) | 1

### 4.2 ESP32 Peripheral Controller Wiring

The single ESP32 peripheral controller has been split into two independent boards to isolate timing-critical UWB ranging and BLE communication from servo PWM jitter contention.

Drivetrain Controller (ESP32 #1)

Listing 6: Drivetrain ESP32 Pin Assignments

// Motor Drivers ( BTS7960 x2 , R_EN / L_EN tied HIGH ):
GPIO25 ( PWM ) -> BTS7960 #1 RPWM | GPIO26 ( PWM ) -> BTS7960 #1 LPWM
GPIO12 ( PWM ) -> BTS7960 #2 RPWM | GPIO13 ( PWM ) -> BTS7960 #2 LPWM

// Steering Servos ( Ackermann linkage ):
GPIO15 -> Left steering servo ( MG995 )
GPIO2 -> Right steering servo ( MG995 )

// Ultrasonic Sensors (HC - SR04 ): GPIO5 TRIG1 / GPIO18 ECHO1 -> Front GPIO19 TRIG2 / GPIO21 ECHO2 -> Left GPIO22 TRIG3 / GPIO23 ECHO3 -> Right GPIO4 TRIG4 / GPIO16 ECHO4 -> Rear

// UWB Modules ( DWM1000 ) x3 :
GPIO32 ( SPI SCK ) -> DWM1000 SCK | GPIO33 ( MOSI ) -> DWM1000 MOSI
GPIO34 ( MISO ) -> DWM1000 MISO
GPIO35 ( CS1 ) -> DWM1000 #1 CS | GPIO36 ( CS2 ) -> DWM1000 #2 CS
GPIO39 ( CS3 ) -> DWM1000 #3 CS

// BLE Module (HC -05) for RSSI person - finding :
GPIO9 | ( TX ) -> HC -05 RX | | GPIO10 ( RX ) -> HC -05 TX

// UART to D - Robotics RDK X5 :
GPIO1 ( TX ) -> RDK X5 UART RX | GPIO3 ( RX ) -> RDK X5 UART TX
Baud rate : 115200

Manipulator Controller (ESP32 #2)

Listing 7: Manipulator ESP32 Pin Assignments

// Robotic Arm Servos ( MG996R x5 + MG90S x1 ): GPIO13 -> Base rotation ( MG996R )
GPIO14 -> Shoulder ( MG996R )
GPIO27 -> Elbow ( MG996R )
GPIO26 -> Wrist pitch ( MG996R ) GPIO25 -> Wrist roll ( MG996R )
GPIO33 -> Gripper ( MG90S )

// Medication Dispenser Servos ( SG90 x4 ):
GPIO16 -> Servo 1 ( Slot A ) | GPIO17 -> Servo 2 ( Slot B )
GPIO18 -> Servo 3 ( Slot C ) | GPIO19 -> Servo 4 ( Slot D )

// TF - Luna ToF Sensor ( UART ) :
GPIO4 ( TX ) -> TF - Luna RX | GPIO5 ( RX ) -> TF - Luna TX

// Water Pump Relay :
GPIO12 -> Relay IN ( peristaltic pump )

// ILI9488 TFT LCD ( Medication Dispenser Touchscreen ):
GPIO33 ( MOSI ) -> TFT MOSI | GPIO34 ( MISO ) -> TFT MISO
GPIO32 ( SCK ) -> TFT SCK | GPIO15 ( CS ) -> TFT CS
GPIO21 ( DC ) -> TFT DC | GPIO22 ( RST ) -> TFT RST
3.3 V -> TFT VCC | GND -> TFT GND

// XPT2046 Touch Controller :

GPIO2 ( CS ) -> XPT2046 T_CS | GPIO35 ( IRQ ) -> XPT2046 T_IRQ
GPIO33 ( MOSI ) -> XPT2046 MOSI | GPIO34 ( MISO ) -> XPT2046 MISO
GPIO32 ( SCK ) -> XPT2046 T_CLK
// ESP32 renders the UI with TFT_eSPI and polls touch coordinates directly .

// UART to D - Robotics RDK X5 ( second serial port ):
GPIO1 ( TX ) -> RDK X5 UART1 RX | GPIO3 ( RX ) -> RDK X5 UART1 TX
Baud rate : 115200

### 4.3 ROS2 Package Structure

HollowRover runs ROS2 Humble Hawksbill on Ubuntu 22.04 Server (64-bit) on the D-Robotics RDK X5, which provides native ROS2 support. The dedicated 10 TOPS NPU/BPU allows SphereAI’s AI inference (Whisper STT, DistilBERT sentiment analysis) to run in parallel with ROS2 Nav2/SLAM on separate silicon, eliminating CPU contention that would occur on a general-purpose SoC. The complete ROS2 workspace is structured as follows:

Listing 8: ROS2 Workspace Structure

hollowrover_ws /
src /
hollowrover_bringup / | <- Launch files for full system
hollowrover_description / | <- URDF robot model
hollowrover_navigation / | <- Nav2 configuration
hollowrover_protocols / | <- Biomarker - triggered action nodes
hollowrover_hardware / | <- ESP32 serial bridge nodes ( x2 )
hollowrover_firebase / | <- Firebase state subscriber
hollowrover_arm / | <- 6- DOF arm control node

### 4.4 SLAM Configuration

HollowRover uses SLAM Toolbox in lifelong mapping mode with the STL-06P TOF LiDAR providing scan data for 2D occupancy grid construction. The TOF-based measurement principle ensures consistent accuracy across the operating range. The critical Nav2 parameters configure the controller frequency at 20.0 Hz, max forward speed of 0.3 m/s, and a safety inflation radius of 0.35 m around obstacles.

### 4.5 UWB Localization

For each registered floor, three DWM1000 UWB anchor modules are mounted at known fixed positions forming a non-collinear triangle. The rover localizes against the anchor set associated with its detected floor, while the UWB tag on the Vital32 wearable can be ranged within the same floor reference. With three anchors, the system performs true 2D trilateration without requiring a last-known-position heuristic, resolving the left-right ambiguity inherent in two-anchor geometry. Floor identity is not inferred from UWB Z-axis geometry; it is supplied by barometric floor discrimination and then used to select the corresponding three-anchor map.

Listing 9: 3-Anchor UWB Trilateration Algorithm

def trilaterate_3anchor (a , b , c , rA , rB , rC ): """
a , b , c : (x , y ) positions of 3 anchors
rA , rB , rC : measured ranges to each anchor Returns : (x , y) estimated position
"""
A = 2 * np . array ([
[b [0] - a [0] , b [1] - a [1]] ,
[c [0] - a [0] , c [1] - a [1]]
])
b_vec = np . array ([
rA **2 - rB **2 + b [0]**2 - a [0]**2 + b [1]**2 - a [1]**2 , rA **2 - rC **2 + c [0]**2 - a [0]**2 + c [1]**2 - a [1]**2 ])
pos = np . linalg . solve (A , b_vec )
return pos [0] , pos [1]

Floor Detection via Barometric Pressure

HollowRover uses a dedicated barometric pressure sensor to determine floor level independently of 2D UWB trilateration. Each registered floor stores a pressure baseline together with its three-anchor UWB geometry. The rover compares its current pressure reading against these calibrated baselines, selects the closest valid floor reference, and only then activates the corresponding SLAM map and UWB anchor set. EntryGuard nodes use the same principle: each node reports its pressure reading and UWB zone identity with an alert, allowing HollowRover to determine which floor and protected area produced the danger or intrusion event. This separates the problem cleanly: barometric pressure identifies the vertical floor context, while three-anchor UWB resolves precise horizontal position on that floor.

### 4.6 BLE RSSI Person-Finding

When the user is outside UWB anchor coverage or in an unmapped area, HollowRover switches to BLE RSSI direction-finding to locate the user. The HC-05 BLE module on the rover measures signal strength from the user’s wearable BLE beacon. By rotating in place and sampling RSSI at multiple headings, the rover estimates the direction of maximum signal strength and navigates toward it. This coarse localization method has lower accuracy than UWB but operates at significantly longer range, making it suitable as a fallback search behavior when precision positioning is unavailable. Once the rover enters UWB coverage, it seamlessly transitions back to trilateration-based navigation.

### 4.7 Drivetrain: Ackermann Steering and Rocker Suspension

HollowRover employs a four-wheel independent steering system using machined steering knuckles at each wheel corner, connected via an Ackermann linkage actuated by two MG995 servos. The Ackermann geometry ensures that the inner wheel turns at a greater angle than the outer wheel during turns (δi > δo), minimizing tire scrub and enabling precise path-following behavior required for SLAM-based navigation. This replaces the original fixed-axle configuration, which relied on skid-steer and provided no independent steering capability.
Each wheel is a 5.6-inch diameter unit with a treaded rubber tire and a four-hole hub with radial spokes, coupled to the Dake DK-37R 315RPM gear motors via M4-threaded axle couplers. The coupler transmits torque from the motor shaft to the wheel hub while allowing straightforward assembly and maintenance.
The suspension system consists of two rocker arms, one per side, each pivoting on a spring-loaded central mount. A differential bar links the left and right rocker assemblies, ensuring that chassis pitch remains balanced when one side encounters an obstacle. The spring-loaded pivots maintain independent wheel-ground contact over bumps, doorway lips, and floor transitions. This passive suspension improves traction and stability without adding active control complexity.

### 4.8 HollowRover Robotic Arm

Mechanical Specification

HollowRover is equipped with a 6-DOF robotic arm mounted on the chassis:
- Joint 1 — Base Rotation: MG996R metal gear servo
- Joint 2 — Shoulder: MG996R metal gear servo
- Joint 3 — Elbow: MG996R metal gear servo
- Joint 4 — Wrist Pitch: MG996R metal gear servo
- Joint 5 — Wrist Roll: MG996R metal gear servo
- Joint 6 — Gripper: MG90S micro servo

Dual-Purpose Design

The arm serves two distinct functions:
(a) Caregiving Assist: The arm retrieves dropped medication or objects from the floor, and hands items (medication, water, personal items) to the user at an accessible height. This reduces the need for the elderly user to bend down or reach for objects.
(b) Security Deterrent — Passive Barrier: When EntryGuard’s face recognition pipeline (Section 5.3, DeepFace) flags an unregistered individual at a monitored chokepoint (e.g., a hallway leading to valuables or sensitive rooms), the arm swings to a blocking position across the pathway. The arm serves as a passive physical barrier that obstructs the intruder’s path.

Mechanical Constraint — LiDAR Occlusion

The arm rests in a folded/stowed position below the STL-06P LiDAR’s scan plane during normal navigation. It only rises to the blocking position when HollowRover is stationary in security-response mode. Navigation and defense states are mutually exclusive: the rover must be stationary before the arm deploys, so no LiDAR occlusion conflict occurs during active navigation.

Trigger Sensor and Detection Pipeline

A TF-Luna single-point ToF sensor (0.2–8m range, UART/I2C interface) is mounted at the designated chokepoint. When the ToF sensor detects a person’s presence, the RGB camera feed is routed into the existing DeepFace recognition pipeline. If the detected face is not matched against registered profiles, the security response is triggered.

Safety Constraint

The robotic arm is a passive physical barrier only. It makes no contact with any person, performs no grasping, restraining, or striking action against intruders, and initiates no autonomous defensive decision. The detection event triggers three simultaneous responses:
1. The arm moves to block the pathway (passive barrier only).
2. An audible alarm is activated.
3. An instant push notification with live camera feed is sent to the guardian’s phone. All escalation decisions beyond these three actions require explicit human authorization, consistent with the mandatory-human-authorization rule stated in Section 2.8.

## 5 SphereAI: Implementation Guide

SphereAI is the affective computing layer of LifeSphere. It implements a TriAgent architecture with three concurrent processing agents fused by a meta-classifier. The Personality Mirror feature has been removed from this version on ethical and privacy grounds; SphereAI learns preferences to improve interaction quality but does not build a deep personality model that could be replicated or shared.

### 5.1 Software Dependencies

Listing 10: SphereAI Python Dependencies

pip install openai - whisper | # Speech -to - text ( Language Agent )
pip install librosa | # Audio feature extraction ( Voice Agent )
pip install transformers torch # NLP sentiment + coherence
pip install scikit - learn | # Meta - classifier
pip install firebase - admin | # Firebase SDK
pip install numpy scipy | # Signal processing
pip install sounddevice | # Microphone capture
pip install pyttsx3 | # Text -to - speech output
pip install luma . oled | # SSD1306 OLED display

### 5.2 Voice Hardware Specification

The original SphereAI specification defined software dependencies (Whisper STT, sounddevice, pyttsx3) but did not specify the physical audio hardware. The complete voice I/O chain is as follows:
- Microphone: INMP441 I2S digital microphone—provides 24-bit audio at up to 48 kHz sampling rate, superior to analog electret microphones for speech recognition due to reduced noise floor and direct digital interface to the ESP32-S3.
- Amplifier and Speaker: MAX98357A I2S Class D amplifier driving a 3W 4 Ω speaker—provides clear voice output for conversation, alert sounds, and adhkar playback.
- Local Wake-Word Engine: An ESP32-S3 runs a lightweight wake-word detection model (ESP-SR) locally, enabling always-listening capability without continuous cloud connectivity or RDK X5 CPU involvement. When the wake word is detected, the ESP32-S3 signals the RDK X5 via UART, which then activates full Whisper STT processing on the audio stream.
- Audio Routing: INMP441 and MAX98357A connect to the ESP32-S3 via I2S (BCLK, WS, DOUT/DIN pins). The ESP32-S3 communicates wake-word events to the RDK X5 via UART at 115200 baud.
This hardware layer fills the gap between the software-defined audio pipeline and the physical audio I/O that was previously unspecified.

### 5.3 TriAgent Fusion Logic

The MetaClassifier applies dynamic weights based on the prior emotional state to fuse outputs from the Language, Voice, and Biology agents.

Listing 11: SphereAI Meta-Classifier

class MetaClassifier :
WEIGHTS = {
’calm ’: | {’ language ’: 0.4 , ’ voice ’: 0.3 , ’ biology ’: 0.3} ,
’ stressed ’: | {’ language ’: 0.2 , ’ voice ’: 0.3 , ’ biology ’: 0.5} ,
’ grief ’: | {’ language ’: 0.3 , ’ voice ’: 0.4 , ’ biology ’: 0.3} ,
’ isolated ’: | {’ language ’: 0.2 , ’ voice ’: 0.2 , ’ biology ’: 0.6} ,
’ cognitive ’: {’ language ’: 0.5 , ’ voice ’: 0.3 , ’ biology ’: 0.2} , }

def fuse ( self , lang_out , voice_out , bio_out , prior_state ):
w = self . WEIGHTS . get ( prior_state , self . WEIGHTS [’ calm ’]) scores = {}
for state in EMOTIONAL_STATES :
scores [ state ] = (
w[ ’ language ’] * lang_out . get ( state , 0) + w[ ’ voice ’] * voice_out . get ( state , 0) + w[ ’ biology ’] * bio_out . get ( state , 0)
)
return max ( scores , key = scores . get ) , scores

## 6 EntryGuard and HollowCore: Implementation Guide

### 6.1 EntryGuard Hardware per Node

Each EntryGuard node runs an ESP32 WROOM-32 equipped with a PIR sensor (HC-SR501), ultrasonic sensor (HC-SR04), fire sensor (KY-026), gas sensor (MQ-2), UWB module, and barometric pressure sensor. All sensor events are published to Firebase together with the node’s UWB zone identity and pressure-derived floor reference. During an intrusion or danger event, these localization fields allow HollowRover to select the correct floor map and navigate to the EntryGuard zone that generated the alert.

Listing 12: EntryGuard Node Firmware

void loop () {
bool motion = digitalRead ( PIR_PIN ); int fire = analogRead ( FIRE_PIN ) ; int gas = analogRead ( GAS_PIN );
long dist = measureUltrasonic () ;
if ( motion && systemMode == ACTIVE )
publishAlert (" motion ", dist , nodeID );
if ( fire > FIRE_THRESHOLD ) {
publishAlert (" fire ", fire , nodeID ); triggerBuzzer () ; }
if ( gas > GAS_THRESHOLD ) {
publishAlert (" gas " , gas , nodeID ); triggerBuzzer () ; }
delay (100) ;
}

### 6.2 HollowCore Wiring

HollowCore uses an ESP32 to control relay modules for appliance operation. It listens to Mosquitto MQTT broker running on the D-Robotics RDK X5 and maps Firebase state variables to relay triggers. The medication dispenser touchscreen connects to the ESP32 through an SPI TFT interface. The ESP32 renders the interface directly with TFT_eSPI and reads touch coordinates from the XPT2046 controller, then relays the resulting manual input commands to Firebase.

Listing 13: HollowCore Pin Assignments

GPIO26 -> Relay 1 IN ( Living room light ) GPIO27 -> Relay 2 IN ( Bedroom light )
GPIO14 -> Relay 3 IN ( AC / fan )
GPIO12 -> Relay 4 IN ( TV power )
GPIO13 -> Relay 5 IN ( Main door lock solenoid )

// ILI9488 TFT LCD + XPT2046 Touch ( Medication Dispenser Manual Input ): GPIO33 ( MOSI ) -> TFT MOSI / XPT2046 MOSI
GPIO34 ( MISO ) -> TFT MISO / XPT2046 MISO
GPIO32 ( SCK ) -> TFT SCK / XPT2046 T_CLK
GPIO15 ( CS ) -> TFT CS
GPIO21 ( DC ) -> TFT DC
GPIO22 ( RST ) -> TFT RST
GPIO2 ( CS ) -> XPT2046 T_CS
GPIO35 ( IRQ ) -> XPT2046 T_IRQ
// TFT_eSPI draws buttons , text fields , dosage controls , and schedule data directly on the ESP32 .
// The ESP32 polls the XPT2046 touch controller , maps touch coordinates to button regions ,
// determines the requested action , and relays it to Firebase :
// / lifesphere / hollowcore / dispenser_manual

// MQTT Topic : lifesphere / hollowcore / command

// Payload : {" device ": " light_1 " , " state ": true }

### 6.3 HollowCore Biometric-to-Environment Mapping

HollowCore’s primary function is translating the shared biological state object into physical environment changes. The mapping logic runs on the ESP32 and triggers relay states based on Firebase field thresholds:

Listing 14: HollowCore Biometric Mapping

void loop () {
if ( Firebase . getJSON ( fbdo , "/ lifesphere / vital32 ") ) { float cortisol = fbdo . jsonObject () [" cortisol_est "]; float skinTemp = fbdo . jsonObject () [" skin_temp "];
float spo2 | = fbdo . jsonObject () [" spo2 "];
float gsr | = fbdo . jsonObject () [" gsr "];
bool | sleepDetected = isSleepState ( hrData , accelData );

if ( cortisol > 18.0) {
setRelay (" light_1 ", WARM_DIM ); | // warm lighting to calm
setRelay (" ac ", LOWER_TEMP ); | // cooler environment
}
if ( gsr > 0.6) {
mqttPublish (" sphereai / command ", " play_calming_audio ") ; }
if ( spo2 < 94.0) {
setRelay (" air_purifier ", ON ) ;
}
if ( sleepDetected ) {
setRelay (" light_1 ", OFF ); setRelay (" light_2 ", OFF ); setRelay (" door_lock " , LOCKED );
}
if ( skinTemp < 35.5) {
setRelay (" ac ", RAISE_TEMP );
}
}
}

### 6.4 HollowCore Financial Anomaly Detection & Biometric Se-

curity

HollowCore extends its monitoring beyond the physical environment to the user’s financial and digital security. By integrating with the user’s banking and subscription services via secure APIs, HollowCore scans incoming transactions and recurring subscriptions in realtime.

Transaction Security Features

- Anomaly Detection: Utilizes an Isolation Forest model trained on the user’s historical spending habits to flag unrecognized, out-of-pattern, or suspicious transactions.
- Smart Notification: Instantly alerts the user via the LifeSphere app and HollowRover OLED, providing transaction details and a one-tap option to freeze the card or dispute the charge.
- Biometric Transaction Authorization: For the user to authorize any new high-risk transaction or subscription manually, HollowCore mandates multi-factor biometric verification. This requires facial recognition (via EntryGuard/HollowRover camera), fingerprint scan, and proximity confirmation from the Vital32 wearable, ensuring maximum financial security.

## 7 Firebase Backend Architecture

The Firebase Realtime Database serves as the central nervous system of LifeSphere. All five subsystems read from and write to a single JSON tree.

### 7.1 Firebase Project Setup

1. Create a new project named LifeSphere at console.firebase.google.com.
2. Enable Realtime Database. Choose region asia-southeast1 (Singapore).
3. Set database rules to authenticated-only access.
4. Download the service account JSON for Python SDK access.
5. Get the Web API key for ESP32 REST API access.

### 7.2 ESP32 Firebase Write (Vital32/EntryGuard)

Listing 15: ESP32 Firebase Write

# include < FirebaseESP32 .h >

# include < WiFi .h >

# define FIREBASE_HOST " your - project . firebaseio . com " # define FIREBASE_AUTH " your - database - secret "

FirebaseData fbdo ;

void writeToFirebase ( SensorData data ) {
Firebase . setFloat ( fbdo , "/ lifesphere / vital32 / heart_rate " , data . hr ); Firebase . setFloat ( fbdo , "/ lifesphere / vital32 / spo2 ", data . spo2 );
Firebase . setBool ( fbdo , "/ lifesphere / vital32 / fall_detected " , data . fall ) ; }

### 7.3 Python Firebase Read (SphereAI/HollowRover)

Listing 16: Python Firebase Read

import firebase_admin
from firebase_admin import credentials , db

cred = credentials . Certificate (’ serviceAccountKey . json ’) firebase_admin . initialize_app ( cred , {
’ databaseURL ’: ’ https :// your - project . firebaseio . com ’ })

ref = db . reference ( ’/ lifesphere / vital32 ’)

def on_vital32_change ( event ) :
data = event . data
if data . get (’ fall_detected ’) : | dispatch_fall_protocol ()
if data . get (’ anomaly_score ’, 0) > 0.9: dispatch_emergency_protocol () if data . get (’ seizure_prob ’, 0) > 0.85: dispatch_seizure_protocol ()

ref . listen ( on_vital32_change )

## 8 AI Model Pipeline: Training and Deployment

All AI models in LifeSphere are trained offline and deployed as TensorFlow Lite models on the respective hardware. The AI pipeline is the brain of the ecosystem, transforming raw sensor data into actionable medical and emotional insights.

Impact on Humanity

The AI Pipeline represents a paradigm shift in personal healthcare. By utilizing multi-timescale inference (short, medium, and long-cycle), the pipeline learns the user’s unique biological baseline. This means LifeSphere doesn’t just compare the user to a generic population—it compares the user to their own healthy state, detecting subtle deviations that precede critical events, thus democratizing predictive healthcare.

### 8.1 Isolation Forest Anomaly Detector

The Isolation Forest model runs on Vital32 (via TFLite) and serves as the primary realtime anomaly detector. It is trained on the user’s own biometric data collected during the first 30 days of normal use.

Listing 17: Isolation Forest Training

from sklearn . ensemble import IsolationForest import numpy as np

def train_isolation_forest ( baseline_data ) : model = IsolationForest (
n_estimators =100 , max_samples = ’ auto ’, contamination =0.05 , random_state =42 )
model . fit ( baseline_data )
return model

def get_anomaly_score ( model , sample ) :
raw = model . score_samples ([ sample ]) [0] return 1 - ( raw + 0.5) # normalize to 0 -1

### 8.2 Pre-Seizure LSTM

The pre-seizure detection LSTM is trained on the CHB-MIT Scalp EEG Dataset and the Epilepsy iEEG Prediction dataset. The model takes 5-minute rolling windows of HRV, accelerometer, and skin temperature features as input.

Listing 18: Pre-Seizure LSTM Model

import tensorflow as tf
from tensorflow . keras . models import Sequential
from tensorflow . keras . layers import LSTM , Dense , Dropout

def build_seizure_model () :
model = Sequential ([
LSTM (64 , input_shape =(300 , 5) , return_sequences = True ) , Dropout (0.3) ,
LSTM (32 , return_sequences = False ) ,
Dropout (0.3) ,
Dense (16 , activation =’ relu ’) ,
Dense (1 , activation = ’ sigmoid ’) # seizure probability ])
model . compile ( optimizer = ’ adam ’,
loss =’ binary_crossentropy ’ , metrics =[ ’ accuracy ’, ’AUC ’]) return model

### 8.3 SphereAI Emotional State Classifier

The Voice Agent utilizes Librosa to extract MFCC, pitch, energy, tempo, and zerocrossing rate. The Language Agent uses a HuggingFace DistilBERT model for sentiment analysis. Cognitive assessment computes unique word ratio, topic repetition, and semantic coherence.

### 8.4 Model Performance Summary

Model | Architecture | Output | Threshold
Anomaly Detector | Isolation | Forest
| (100 trees) | Score 0–1 | 0.7 / 0.9
Pre-Seizure LSTM | 2×LSTM (64,32) + Dense | Prob 0–1 | 0.85
Emotional Classifier | Weighted 3-stream fusion | State category | Highest
Cortisol Estimator | Gradient | Boost
| (200 trees) | ng/dL est. | 15m update

Biological Age Clock Ensemble (RF +
| XGBoost) | Age in years | Daily update
Cognitive Tracker | Statistical | drift
| (CUSUM) | Deviation score | 2-sigma

## 9 Mathematical Foundations

### 9.1 Biometric Signal Processing

Heart Rate Variability is computed from the RR interval time series extracted from the MAX30102 PPG waveform. The primary HRV metrics are:

RMSSD =

vuut
1
N − 1

N

X⁻¹

i=1

(RRi+1 − RRi)

2
(1)

LF/HF =

PLF [0.04–0.15 Hz]
PHF [0.15–0.40 Hz]

(2)

Cest = f(RMSSD, GSRbaseline, Tskin, sleep_efficiency) | (3)

### 9.2 Isolation Forest Anomaly Score

s(x, n) = 2⁻

E[h(x)]
c(n) | (4)

c(n) = 2H(n − 1) −

2(n − 1)
n
where H(n) = ln(n) + 0.5772 | (5)

Scores s(x, n) > 0.7 trigger a soft alert. Scores > 0.9 trigger an emergency protocol dispatch.

### 9.3 Medication Adherence Entropy

H(X) = −

X

i

p(xi) log2

(p(xi)) | (6)

High entropy indicates irregular adherence. Low entropy indicates consistent adherence.

### 9.4 UWB 3-Anchor Trilateration

With three anchors at positions a = (ax, ay), b = (bx, by), c = (cx, cy) and measured ranges rA, rB, rC:

(x − ax)

2 + (y − ay)

2 = r

2
A | (7)

(x − bx)

2 + (y − by)

2 = r

2
B | (8)

(x − cx)

2 + (y − cy)

2 = r

2
C | (9)

Subtracting the first equation from the second and third yields a linear system Ax = b:
2(bx − ax) 2(by − ay)
2(cx − ax) 2(cy − ay)

x
y
=
r

2
A − r

2
B + b

2
x − a

2
x + b

2
y − a

2
y
r

2
A − r

2
C + c

2
x − a

2
x + c

2
y − a

2
y
| (10)
x
y
= A⁻¹b | (11)

Three non-collinear anchors guarantee a unique 2D solution, eliminating the left-right ambiguity present in the two-anchor case.

### 9.5 Barometric Floor Detection

Floor-level discrimination uses barometric pressure P measured by HollowRover and by the fixed EntryGuard nodes. Each registered floor maintains a calibrated reference pressure Pf paired with its three-anchor UWB map:

zfloor =

P0 − Pmeasured

∆Pfloor
(12)

where P0 is a calibrated reference pressure and ∆Pfloor is the measured pressure difference between adjacent registered floors. In deployment, the rover selects the floor whose calibrated pressure baseline is closest to its current reading, then loads that floor’s SLAM map and three-anchor UWB geometry. EntryGuard alerts include the node’s own floor-pressure reference and UWB zone identifier, providing an independent target-floor confirmation before the rover begins a security or hazard response. UWB is therefore used for precise 2D position on the selected floor, while barometric pressure provides the vertical floor context required for multi-floor operation.

## 10 Prescription OCR and Automated Medication Reminders

A critical challenge in elderly medication management is the initial setup burden: manually entering every medicine name, dosage, and timing is error-prone and discourages adoption. LifeSphere addresses this through a one-time prescription photograph workflow. The user photographs their prescription once using the companion mobile app, and the system automatically extracts and creates a complete medication schedule. Manual entry remains available as an alternative, and all extracted data is fully editable to account for handwriting recognition errors. For users who prefer not to use the phone app, a 3.5-inch 480x320 ILI9488 SPI TFT LCD with an XPT2046 touch controller on the rover itself provides a direct manual input interface. This is a raw display interface with no onboard UI processor; the ESP32 handles all UI rendering and touch-detection logic using TFT_eSPI and the XPT2046 touch interface.

Feature Overview

- User photographs prescription once using the companion mobile app (phone-side OCR processing).
- Vision AI model extracts: medicine name, dosage, frequency, duration, instructions.
- Medication schedule is automatically created in Firebase and synced to HollowRover.
- User reviews and edits extracted data via the mobile app before confirming.
- Manual Fallback: A 3.5-inch 480x320 ILI9488 SPI TFT LCD with an XPT2046 touch controller on the rover’s medication dispenser allows direct medication selection, dosage confirmation, and schedule review without a phone. The raw TFT display is driven directly by the ESP32 using the TFT_eSPI Arduino library; the ESP32 renders the interface and polls the XPT2046 touch controller, maps touch coordinates to on-screen controls, and relays the resulting actions to Firebase.
- HollowRover begins autonomous medication delivery on the confirmed schedule.

### 10.1 System Overview

The prescription OCR pipeline runs on the companion mobile app (phone-side), using a combination of image preprocessing, an OCR engine, and a large language model for structured data extraction. The pipeline is designed to handle the notorious variability of doctor handwriting by using an LLM to interpret context rather than relying on raw OCR output alone. Extracted data is pushed to Firebase, where HollowRover subscribes and populates the local dispenser schedule.

### 10.2 OCR Pipeline and Data Extraction

Listing 19: Prescription OCR Pipeline (Phone-Side)

import pytesseract , cv2 , base64 , requests from PIL import Image
import firebase_admin
from firebase_admin import credentials , db

cred = credentials . Certificate (’ serviceAccountKey . json ’) firebase_admin . initialize_app ( cred , {
’ databaseURL ’: ’ https :// your - project . firebaseio . com ’ })

def extract_prescription ( image_path ):
img = cv2 . imread ( image_path )
gray = cv2 . cvtColor ( img , cv2 . COLOR_BGR2GRAY ) gray = cv2 . adaptiveThreshold (
gray , 255 , cv2 . ADAPTIVE_THRESH_GAUSSIAN_C ,
cv2 . THRESH_BINARY , 31 , 10
)
text = pytesseract . image_to_string ( gray , lang =’ eng ’) # LLM contextual extraction ( runs on phone or cloud ) meds = llm_extract_medications ( text )
return meds

def llm_extract_medications ( raw_text ) :
# Structured extraction via LLM to handle handwriting prompt = f " Extract medicines from this prescription text . Return JSON : [{{ name , dosage , frequency , duration }}] Text : { raw_text }"

response = call_llm ( prompt )
return parse_json ( response )

def sync_to_firebase ( meds ):
ref = db . reference ( ’/ lifesphere / hollowcore / med_schedule ’) ref . set ( meds )

### 10.3 ILI9488 TFT + XPT2046 Manual Fallback

When phone-side OCR is not used, the 3.5-inch 480x320 ILI9488 SPI TFT LCD on the rover’s medication dispenser provides a direct manual input interface. The ILI9488 is a raw display controller with no onboard processor for application-level UI handling. The ESP32 renders medication slots, dosage fields, and timing controls directly using the TFT_eSPI Arduino library. A typical XPT2046 touch controller provides touch coordinates through a separate chip-select and optional interrupt line; the ESP32 polls the touch controller, maps the coordinates to on-screen button regions, determines the requested action, and writes the resulting manual schedule entry to Firebase.

Listing 20: ILI9488 TFT + XPT2046 Touch Handler (Manipulator ESP32)

void handleDispenserTouch () {
if ( touchAvailable () ) {
TouchPoint p = readXPT2046Touch () ; int x = mapTouchX (p. x);
int y = mapTouchY (p. y);

if ( insideButton (x , y , slotAButton )) { selectedSlot = "A ";
}

if ( insideButton (x , y , confirmButton )) {
renderConfirmationState () ;
Firebase . setJSON ( fbdo , "/ lifesphere / hollowcore / dispenser_manual " , buildManualSchedulePayload ( selectedSlot , dose , time )); }
}
}

void drawDispenserUI () {
tft . fillScreen ( TFT_BLACK ) ;
tft . drawString (" Medication ", 20 , 20) ; drawMedicationSlots () ;
drawDosageFields () ;
drawScheduleControls () ;
drawButtonRegions () ;
}

## 11 Conclusion

LifeSphere demonstrates that a fully integrated, AI-powered autonomous caregiving ecosystem is achievable at a accessible cost point using commercially available hardware and open-source software frameworks. By unifying health monitoring (Vital32), physical response (HollowRover), emotional intelligence (SphereAI), perimeter security (Entry-Guard), and biology-responsive automation (HollowCore) around a single shared biological state backbone, the system achieves a level of proactive, multi-dimensional care that no combination of standalone devices can replicate.
The key technical contributions of this work include: (1) a multi-timescale AI inference pipeline that learns individual biological baselines rather than relying on populationlevel thresholds; (2) a ROS2-based autonomous mobile platform with dedicated NPU compute enabling parallel SLAM navigation and AI inference without CPU contention;
(3) a trimodal emotional state classifier fusing language, voice, and biomarker signals with context-adaptive weighting; (4) a passive physical barrier system via a 6-DOF robotic arm that enforces security boundaries without making human contact; and (5) a prescription OCR pipeline that eliminates the medication setup barrier for elderly users.
LifeSphere does not require the user to interact with technology. It requires technology to respond to the user’s biology. This principle—that the most vulnerable members of society should not need to learn complex interfaces to receive care—drives every architectural decision in this system. From the zero-interaction Vital32 wearable to the autonomous HollowRover dispatch protocols, the system is designed to disappear into the background of daily life while continuously protecting the user across medical, physical, emotional, and environmental dimensions.
Future work includes extending the biological state model with additional sensor modalities, integrating legged locomotion for multi-floor navigation, and conducting longitudinal user studies to validate predictive health model accuracy in real-world deployment conditions.

## References

[1] Liu, F.T., Ting, K.M., & Zhou, Z.H. (2008). Isolation Forest. IEEE International Conference on Data Mining, 413–422.
[2] Hochreiter, S. & Schmidhuber, J. (1997). Long Short-Term Memory. Neural Computation, 9(8), 1735–1780.
[3] Devlin, J., Chang, M.W., Lee, K., & Toutanova, K. (2019). BERT: Pre-training of Deep Bidirectional Transformers for Language Understanding. NAACL-HLT, 4171– 4186.
[4] Radford, A., Kim, J.W., Xu, T., et al. (2023). Robust Speech Recognition via Large-Scale Weak Supervision. ICML.
[5] Bosse, T., Kester, L., & de Man, J. (2022). ROS2 Navigation: From SLAM to Nav2. IEEE Robotics & Automation Magazine, 29(3), 56–67.
[6] Goldberger, A.L., Amaral, L.A.N., Glass, L., et al. (2000). PhysioBank, PhysioToolkit, and PhysioNet. Circulation, 101(23), e215–e220.
[7] Shoeb, A.H. (2009). Application of Machine Learning to Epileptic Seizure Detection. M.S. Thesis, MIT.
[8] Smith, S.W. (1997). The Scientist and Engineer’s Guide to Digital Signal Processing. California Technical Publishing.
[9] LDROBOT. (2024). STL-06P DTOF LiDAR Datasheet. https://www.ldrobot. com (https://www.ldrobot.com)
[10] D-Robotics. (2024). RDK X5 Developer Kit Technical Reference Manual. https: //www.d-robotics.cc
[11] Decawave / Qorvo. (2016). DW1000 User Guide. Decawave Ltd.
[12] Ai-Thinker. (2024). BU03 DW3000 UWB Positioning Module Datasheet. https: //www.ai-thinker.com
[13] CEVA / Hillcrest Labs. (2020). BNO080 9-Axis IMU with Sensor Fusion Datasheet. https://www.ceva-ip.com
[14] Bodmer. (2024). TFT_eSPI Library for Arduino/ESP32. https://github.com/Bodmer/TFT_eSPI (https://github.com/Bodmer/TFT_eSPI)
[15] XPT2046. (2014). Resistive Touch Screen Controller Datasheet.
[16] Ilitek. (2011). ILI9488 TFT LCD Single Chip Driver Datasheet.
[17] Espressif Systems. (2023). ESP-SR: Speech Recognition Framework for ESP32-S3. https://github.com/espressif/esp-sr
[18] Google. (2024). Firebase Realtime Database Documentation. https://firebase.google.com/docs/database (https://firebase.google.com/docs/database)

[19] Liu, W., Wen, Y., Yu, Z., & Yang, M. (2017). Large-Margin Softmax Loss for Convolutional Neural Networks. ICML, 507–516.
[20] McFee, B., Raffel, C., Liang, D., et al. (2015). librosa: Audio and Music Signal Analysis in Python. Proc. SciPy, 18–24.
[21] Tesseract OCR. (2024). Tesseract Open Source OCR Engine. https://github.com/tesseract-ocr/tesseract (https://github.com/tesseract-ocr/tesseract)

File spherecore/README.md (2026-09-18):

# SphereCore

> **Download the app:** the release APK is built to [`build/app/outputs/apk/release/app-release.apk`](build/app/outputs/apk/release/app-release.apk)

**The companion app of the [LifeSphere](../README.md) ecosystem** — *An AI-Powered Autonomous Caregiving Ecosystem.*

SphereCore is the Flutter mobile/web app for LifeSphere. The ecosystem itself is designed to be zero-interaction for the elderly user — technology responding to biology, not the other way around — so SphereCore is the window into it for guardians, family members, and the users themselves.

## What It Does

- **Dashboard** — live view of the shared biological state object streamed from Firebase Realtime Database: heart rate, SpO₂, skin temperature, HRV, anomaly score, emotional state, and subsystem statuses (Vital32, HollowRover, SphereAI, EntryGuard, HollowCore).
- **Vital32 monitoring** — dedicated screen for the wearable's real-time metrics and health trends.
- **Medication reminders** — review and edit schedules extracted by the prescription OCR pipeline, confirm them before HollowRover starts autonomous delivery, and track adherence logs.
- **Control** — HollowCore appliance control (lights, AC/fan, TV, door lock) and ecosystem mode switching (e.g., Absence Mode).
- **Members / Remote Guardian** — guardians add dependent users, define monitoring instructions for SphereAI and HollowCore, and receive alerts (falls, intrusions, anomalies, digital-safety events).
- **Location & pins** — GPS targets and virtual pins used for location-aware features and UWB-anchored home mapping.
- **Auth & profiles** — Firebase Authentication with registered user profiles (also cross-referenced by EntryGuard's face recognition).

## Tech Stack

- **Flutter** (Android / iOS / Web / Linux / macOS / Windows)
- **Firebase** — Auth, Realtime Database (the ecosystem's central nervous system), Storage
- Provider-based state management, local notifications for reminders

## Project Structure

```
lib/
├── main.dart / bootstrap/    # App entry & initialization
├── firebase/                 # Firestore rules & indexes
├── models/                   # Member, medicine, GPS target, virtual pin
├── providers/                # Pin & theme providers
├── screens/
│   ├── auth/                 # Login & registration
│   ├── dashboard/            # Main dashboard, reminders, pins
│   ├── vital32/              # Wearable vitals screen
│   ├── control/              # HollowCore appliance control
│   ├── members/              # Guardian / member management
│   └── profile/              # User profile
├── services/                 # Auth, database, health, reminders,
│                             # notifications, location, members
├── themes/                   # App theming
└── widgets/                  # Shared UI components
```

## Getting Started

1. Install the [Flutter SDK](https://docs.flutter.dev/get-started/install).
2. Configure Firebase for your own project (`flutterfire configure`) — the app expects a Realtime Database following the LifeSphere schema under `/lifesphere/` (see Section 7 of the [research PDF](../An%20AI-%20Powered%20Autonomous%20Caregiving%20Ecosystem.pdf)).
3. Run:

```bash
flutter pub get
flutter run
```

## Part of LifeSphere

SphereCore is one piece of a five-subsystem ecosystem built around a single shared biological state backbone:

**Vital32** (biosensing) · **HollowRover** (physical response) · **SphereAI** (emotional intelligence) · **EntryGuard** (perimeter security) · **HollowCore** (biology-responsive automation)

See the [main README](../README.md) and the full research & build document for the complete architecture.

---

**Team Fälschen** — Faiyaz Bin Iqbal · *"Forged. Wired. Perfected"*

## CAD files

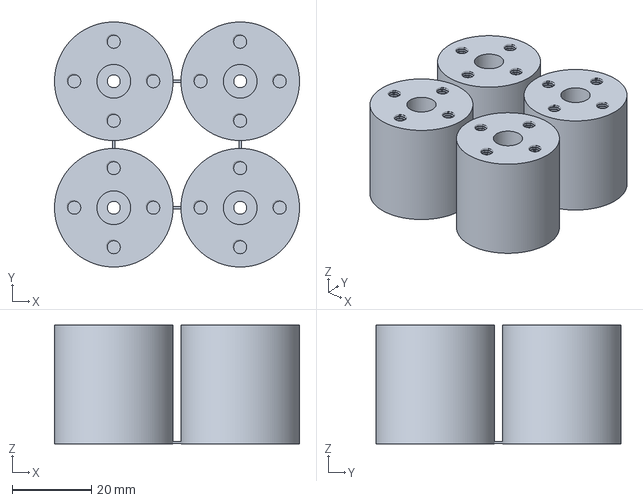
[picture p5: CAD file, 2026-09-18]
FinalCouplerShaft.3mf
62.0 x 62.0 x 30.0 mm

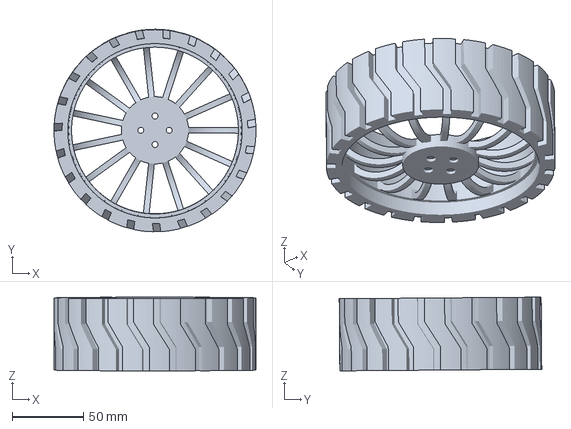
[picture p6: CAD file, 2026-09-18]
Final Wheel 5.6.3mf
142.2 x 142.6 x 51.9 mm

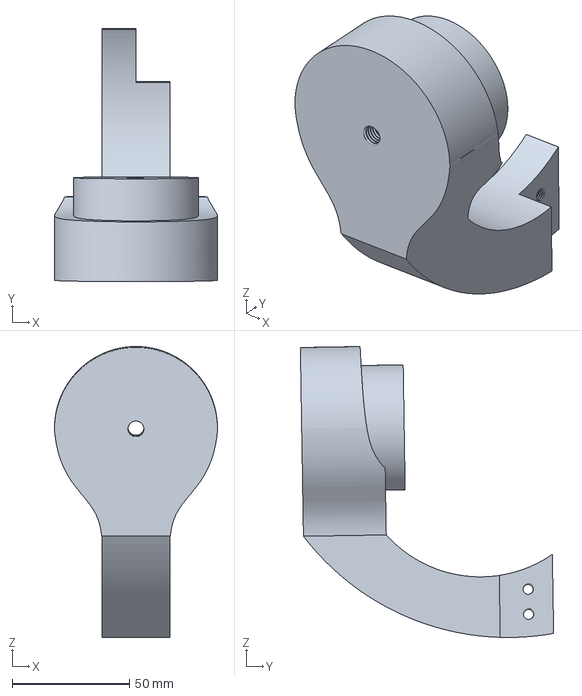
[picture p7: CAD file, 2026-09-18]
Connector for steering.3mf
69.8 x 108.2 x 124.3 mm

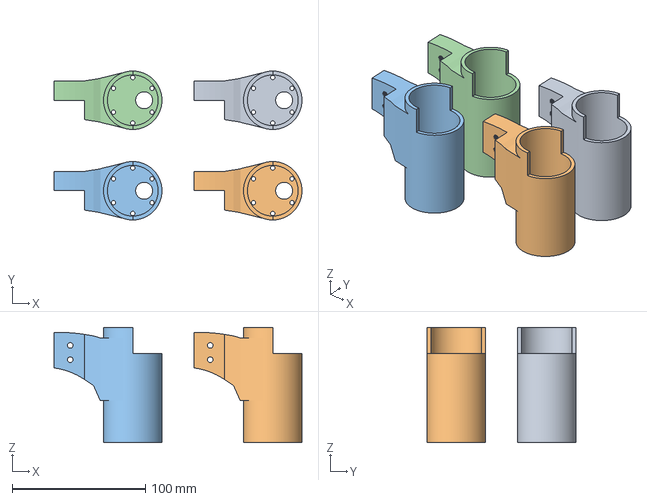
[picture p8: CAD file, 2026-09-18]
Motor Housing.3mf
186.1 x 111.8 x 86.5 mm
Motor Housing.stl x 4

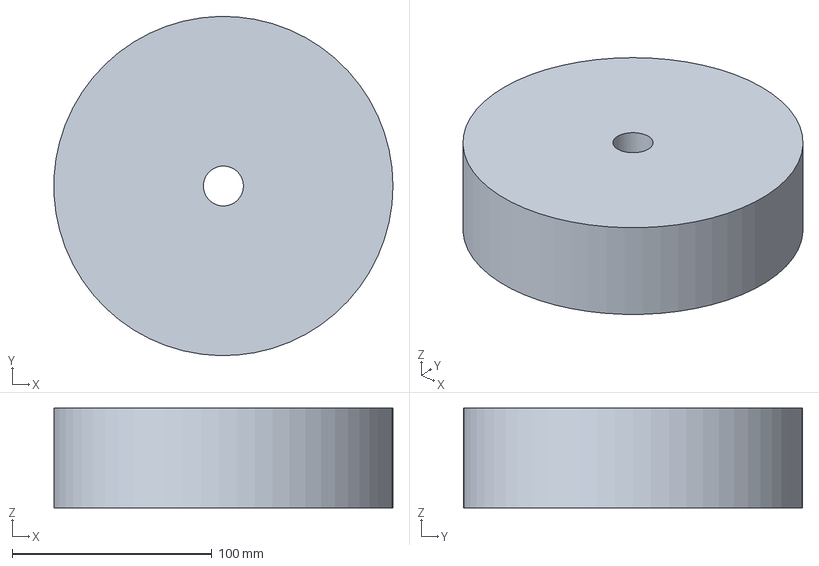
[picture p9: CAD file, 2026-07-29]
MedicineDispenser.FCStd
169.7 x 169.7 x 50.0 mm

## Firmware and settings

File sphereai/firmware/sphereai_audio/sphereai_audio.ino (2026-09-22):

#include <driver/i2s.h>
#include <esp_log.h>
#include <string.h>
#include "config.h"
#include "compat.h"

#define MIC_PORT I2S_NUM_1
#define SPK_PORT I2S_NUM_0

static String lineBuf;
alignas(4) static uint8_t playBuf[PLAY_CHUNK];
alignas(4) static int16_t stereoBuf[PLAY_CHUNK];
alignas(4) static int32_t rxBuf[RX_FRAMES];
alignas(4) static int16_t outBuf[RX_FRAMES];
static bool btnWasDown = false;
static uint32_t btnLastMs = 0;

static void sendLine(const char *s) {
  Serial.print(s);
  Serial.print('\n');
}

static bool readLine(String &out) {
  while (Serial.available()) {
    char c = (char)Serial.read();
    if (c == '\n') {
      out = lineBuf;
      lineBuf = "";
      out.trim();
      return true;
    }
    if (c != '\r') {
      lineBuf += c;
      if (lineBuf.length() > 64) {
        lineBuf = "";
      }
    }
  }
  return false;
}

static bool startMic() {
  i2s_config_t cfg;
  memset(&cfg, 0, sizeof(cfg));
  cfg.mode = (i2s_mode_t)(I2S_MODE_MASTER | I2S_MODE_RX);
  cfg.sample_rate = SAMPLE_RATE;
  cfg.bits_per_sample = I2S_BITS_PER_SAMPLE_32BIT;
  cfg.channel_format = I2S_CHANNEL_FMT_ONLY_LEFT;
  cfg.communication_format = I2S_COMM_FORMAT_STAND_I2S;
  cfg.intr_alloc_flags = ESP_INTR_FLAG_LEVEL1;
  cfg.dma_buf_count = 8;
  cfg.dma_buf_len = 256;
  cfg.use_apll = false;

  i2s_pin_config_t pins;
  memset(&pins, 0, sizeof(pins));
  setMck(pins, 0);
  pins.bck_io_num = PIN_MIC_BCLK;
  pins.ws_io_num = PIN_MIC_WS;
  pins.data_out_num = I2S_PIN_NO_CHANGE;
  pins.data_in_num = PIN_MIC_DIN;

  if (i2s_driver_install(MIC_PORT, &cfg, 0, NULL) != ESP_OK) {
    return false;
  }
  if (i2s_set_pin(MIC_PORT, &pins) != ESP_OK) {
    i2s_driver_uninstall(MIC_PORT);
    return false;
  }
  return true;
}

static bool startSpk() {
  i2s_config_t cfg;
  memset(&cfg, 0, sizeof(cfg));
  cfg.mode = (i2s_mode_t)(I2S_MODE_MASTER | I2S_MODE_TX);
  cfg.sample_rate = SAMPLE_RATE;
  cfg.bits_per_sample = I2S_BITS_PER_SAMPLE_16BIT;
  cfg.channel_format = I2S_CHANNEL_FMT_RIGHT_LEFT;
  cfg.communication_format = I2S_COMM_FORMAT_STAND_I2S;
  cfg.intr_alloc_flags = ESP_INTR_FLAG_LEVEL1;
  cfg.dma_buf_count = 8;
  cfg.dma_buf_len = 256;
  cfg.use_apll = false;
  cfg.tx_desc_auto_clear = true;

  i2s_pin_config_t pins;
  memset(&pins, 0, sizeof(pins));
  setMck(pins, 0);
  pins.bck_io_num = PIN_AMP_BCLK;
  pins.ws_io_num = PIN_AMP_LRC;
  pins.data_out_num = PIN_AMP_DIN;
  pins.data_in_num = I2S_PIN_NO_CHANGE;

  if (i2s_driver_install(SPK_PORT, &cfg, 0, NULL) != ESP_OK) {
    return false;
  }
  if (i2s_set_pin(SPK_PORT, &pins) != ESP_OK) {
    i2s_driver_uninstall(SPK_PORT);
    return false;
  }
  return true;
}

static void doRecord(uint32_t ms) {
  const uint32_t totalBytes = ms * 32;
  bool ok = startMic();

  Serial.print("AUD ");
  Serial.print(totalBytes);
  Serial.print('\n');

  uint32_t remaining = totalBytes;
  if (ok) {
    size_t gotBytes = 0;
    uint32_t settleUntil = millis() + MIC_SETTLE_MS;
    while (millis() < settleUntil) {
      i2s_read(MIC_PORT, rxBuf, sizeof(rxBuf), &gotBytes, pdMS_TO_TICKS(100));
    }
    while (remaining >= 2) {
      size_t wantSamples = remaining / 2;
      if (wantSamples > RX_FRAMES) {
        wantSamples = RX_FRAMES;
      }
      gotBytes = 0;
      i2s_read(MIC_PORT, rxBuf, wantSamples * 4, &gotBytes, pdMS_TO_TICKS(500));
      size_t n = gotBytes / 4;
      if (n == 0) {
        break;
      }
      for (size_t i = 0; i < n; i++) {
        int32_t v = rxBuf[i] >> MIC_SHIFT;
        if (v > 32767) {
          v = 32767;
        }
        if (v < -32768) {
          v = -32768;
        }
        outBuf[i] = (int16_t)v;
      }
      Serial.write((uint8_t *)outBuf, n * 2);
      remaining -= n * 2;
    }
    i2s_driver_uninstall(MIC_PORT);
  }

  memset(outBuf, 0, sizeof(outBuf));
  while (remaining > 0) {
    size_t n = remaining > sizeof(outBuf) ? sizeof(outBuf) : remaining;
    Serial.write((uint8_t *)outBuf, n);
    remaining -= n;
  }
  sendLine("OK");
}

static void doPlay(uint32_t total) {
  if (!startSpk()) {
    sendLine("ERR spk_init");
    return;
  }
  sendLine("RDY");

  uint32_t remaining = total;
  while (remaining > 0) {
    size_t want = remaining > PLAY_CHUNK ? PLAY_CHUNK : remaining;
    size_t got = 0;
    uint32_t lastData = millis();
    while (got < want && millis() - lastData < 3000) {
      int n = Serial.readBytes(playBuf + got, want - got);
      if (n > 0) {
        got += n;
        lastData = millis();
      }
    }
    if (got < want) {
      break;
    }
    size_t samples = got / 2;
    const int16_t *in = (const int16_t *)playBuf;
    for (size_t i = 0; i < samples; i++) {
      stereoBuf[2 * i] = in[i];
      stereoBuf[2 * i + 1] = in[i];
    }
    size_t written = 0;
    i2s_write(SPK_PORT, stereoBuf, samples * 4, &written, portMAX_DELAY);
    Serial.write('K');
    remaining -= got;
  }
  delay(150);
  i2s_driver_uninstall(SPK_PORT);
  sendLine("DONE");
}

static void handleCommand(const String &cmd) {
  if (cmd == "PING") {
    sendLine("PONG");
    return;
  }
  if (cmd.startsWith("REC ")) {
    long ms = cmd.substring(4).toInt();
    if (ms < 100 || ms > MAX_REC_MS) {
      sendLine("ERR bad_ms");
      return;
    }
    doRecord((uint32_t)ms);
    return;
  }
  if (cmd.startsWith("PLAY ")) {
    long n = cmd.substring(5).toInt();
    if (n < 2 || n > MAX_PLAY_BYTES || (n & 1)) {
      sendLine("ERR bad_len");
      return;
    }
    doPlay((uint32_t)n);
    return;
  }
  sendLine("ERR unknown");
}

static void pollButton() {
  bool down = digitalRead(PIN_BTN) == LOW;
  uint32_t now = millis();
  if (down && !btnWasDown && now - btnLastMs > 250) {
    btnLastMs = now;
    sendLine("EVT BTN");
  }
  btnWasDown = down;
}

void setup() {
  esp_log_level_set("*", ESP_LOG_NONE);
  Serial.setRxBufferSize(8192);
  Serial.begin(SERIAL_BAUD);
  Serial.setTimeout(1000);
  pinMode(PIN_BTN, INPUT_PULLUP);
}

void loop() {
  String cmd;
  if (readLine(cmd)) {
    handleCommand(cmd);
  }
  pollButton();
}

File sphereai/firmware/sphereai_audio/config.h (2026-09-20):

#pragma once

#define SAMPLE_RATE 16000
#define SERIAL_BAUD 921600

#define PIN_MIC_BCLK 5
#define PIN_MIC_WS 4
#define PIN_MIC_DIN 6

#define PIN_AMP_BCLK 15
#define PIN_AMP_LRC 16
#define PIN_AMP_DIN 7

#define PIN_BTN 0

#define MIC_SHIFT 12
#define MIC_SETTLE_MS 120

#define PLAY_CHUNK 1024
#define RX_FRAMES 512
#define MAX_REC_MS 30000
#define MAX_PLAY_BYTES 4000000

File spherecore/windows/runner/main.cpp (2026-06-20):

#include <flutter/dart_project.h>
#include <flutter/flutter_view_controller.h>
#include <windows.h>

#include "flutter_window.h"
#include "utils.h"

int APIENTRY wWinMain(_In_ HINSTANCE instance, _In_opt_ HINSTANCE prev,
                      _In_ wchar_t *command_line, _In_ int show_command) {
  // Attach to console when present (e.g., 'flutter run') or create a
  // new console when running with a debugger.
  if (!::AttachConsole(ATTACH_PARENT_PROCESS) && ::IsDebuggerPresent()) {
    CreateAndAttachConsole();
  }

  // Initialize COM, so that it is available for use in the library and/or
  // plugins.
  ::CoInitializeEx(nullptr, COINIT_APARTMENTTHREADED);

  flutter::DartProject project(L"data");

  std::vector<std::string> command_line_arguments =
      GetCommandLineArguments();

  project.set_dart_entrypoint_arguments(std::move(command_line_arguments));

  FlutterWindow window(project);
  Win32Window::Point origin(10, 10);
  Win32Window::Size size(1280, 720);
  if (!window.Create(L"LifeSphere", origin, size)) {
    return EXIT_FAILURE;
  }
  window.SetQuitOnClose(true);

  ::MSG msg;
  while (::GetMessage(&msg, nullptr, 0, 0)) {
    ::TranslateMessage(&msg);
    ::DispatchMessage(&msg);
  }

  ::CoUninitialize();
  return EXIT_SUCCESS;
}

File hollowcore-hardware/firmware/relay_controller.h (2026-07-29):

#pragma once

#include <Arduino.h>

#define RELAY_COUNT 5
#define RELAY_ACTIVE_LOW 1

struct RelayChannel {
  uint8_t gpio;
  const char *name;
  bool state;
};

static RelayChannel relayChannels[RELAY_COUNT] = {
  {26, "Living room light", false},
  {27, "Bedroom light", false},
  {14, "AC / fan", false},
  {12, "TV power", false},
  {13, "Main door lock", false},
};

inline uint8_t relayLevel(bool on) {
#if RELAY_ACTIVE_LOW
  return on ? LOW : HIGH;
#else
  return on ? HIGH : LOW;
#endif
}

inline void relayInit() {
  for (uint8_t i = 0; i < RELAY_COUNT; i++) {
    pinMode(relayChannels[i].gpio, OUTPUT);
    digitalWrite(relayChannels[i].gpio, relayLevel(false));
    relayChannels[i].state = false;
  }
}

inline int relayIndexForGpio(int gpio) {
  for (uint8_t i = 0; i < RELAY_COUNT; i++) {
    if (relayChannels[i].gpio == gpio) return i;
  }
  return -1;
}

inline bool relayApply(int gpio, bool on) {
  int index = relayIndexForGpio(gpio);
  if (index < 0) return false;
  if (relayChannels[index].state == on) return true;

  digitalWrite(relayChannels[index].gpio, relayLevel(on));
  relayChannels[index].state = on;

  Serial.printf("[relay] GPIO%-2d %-18s -> %s\n", gpio, relayChannels[index].name,
                on ? "ON" : "OFF");
  return true;
}

inline void relayAllOff() {
  for (uint8_t i = 0; i < RELAY_COUNT; i++) {
    digitalWrite(relayChannels[i].gpio, relayLevel(false));
    relayChannels[i].state = false;
  }
}

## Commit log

2026-07-10 did some changes final changes
    [.wakatime.cfg]
2026-07-29 README.md change
    [MedicineDispenser.FCStd]
2026-10-22 sphereai: button mode, port picker, debug prints, auto mode; misc firmware updates
